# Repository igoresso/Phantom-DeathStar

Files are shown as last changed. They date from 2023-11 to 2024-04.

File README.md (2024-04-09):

<p align="center">
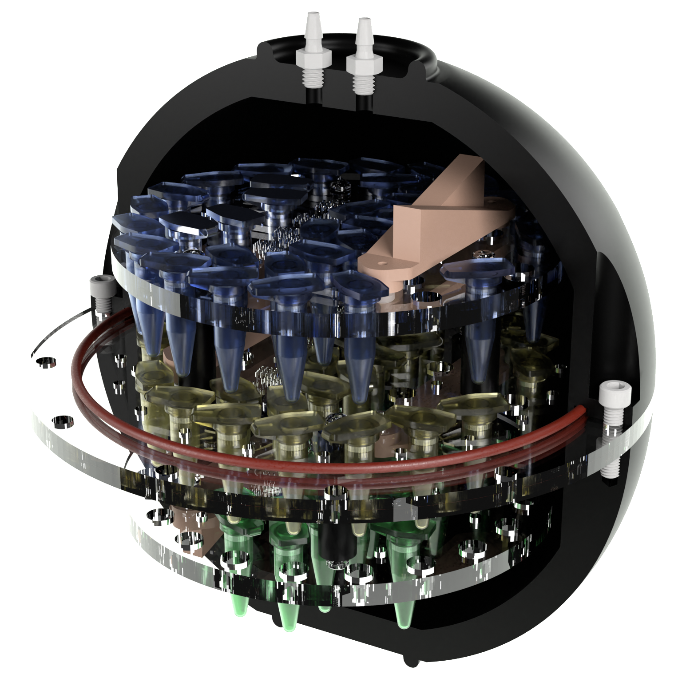
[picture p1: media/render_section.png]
Death Star phantom
  
</p>

# "Death Star" Imaging Phantom 

Welcome to our GitHub repository showcasing the development of a universal MRI imaging phantom, meticulously crafted to cater to a spectrum of research and clinical needs. This phantom presents a multilayered architecture nestled within a spherical shell, promising versatility and adaptability for MRI experimentation and calibration endeavours.

## Features

- Multilayered structure enclosed in a spherical shell
- Outer diameter of 170mm, optimised for compatibility with smaller head coils
- Three layers with multiple mounting holes for various modules and a coarse resolution grid on each
- Top and bottom layers affixed to the middle disc, snugly ensconced between the hemispheres, and reinforced with two silicone o-rings to prevent leakage
- Two tube fittings facilitate easy assembly and disassembly, with one designated for air release during refilling
- Utilising 0.5mL Eppendorf tubes to store any liquids of interest such as T1, T2, or proton density arrays
- The spherical shell is machined on a CNC lathe, while the discs are laser-cut from a 6mm acrylic sheet
- To achieve the desired precision, the resolution grids on the discs are added using a CNC mill, ensuring accuracy

## Additional modules

- Each disc features mounting holes for additional modules, facilitating further customisation and experimentation.
- Extra modules can be 3D printed using a consumer SLA printer
- Two modules are provided: a fine-resolution grid and a slice profile double-wedge
- A template for custom module design is provided

## Bill of Materials

| Part | Quantity |
| --- | --- |
| Acetal rod 250mm (180mm diameter) | 1 |
| Acetal rod 100mm (10mm diameter) | 1 |
| Acrylic sheet 6mm | 1 |
| Glass-Filled Nylon Socket Head Screws M5×0.8, 20mm | 12 |
| Impact-Resistant Polycarbonate Pan Head Phillips Screws M3×0.5, 10mm | 24 |
| Tight-Seal Moisture-Resistant Acetal Barbed Tube Fitting M6×1 | 2 |
| Eppendorf tube 0.5ml | As required |

## Assembly video

https://github.com/igoresso/Phantom-DeathStar/assets/33253240/f2b40d54-d948-43c9-96b6-33f2290663dc

## Acknowledgements

The authors acknowledge the facilities and scientific and technical assistance of the National Imaging Facility, a National Collaborative Research Infrastructure Strategy (NCRIS) capability, at the Melbourne Brain Centre Imaging Unit, University of Melbourne.

## Licensing

The materials are shared under the Creative Commons license which enables reusers to distribute, remix, adapt, and build upon the material in any medium or format for noncommercial purposes only, and only so long as attribution is given to the creator. If you remix, adapt, or build upon the material, you must license the modified material under identical terms.

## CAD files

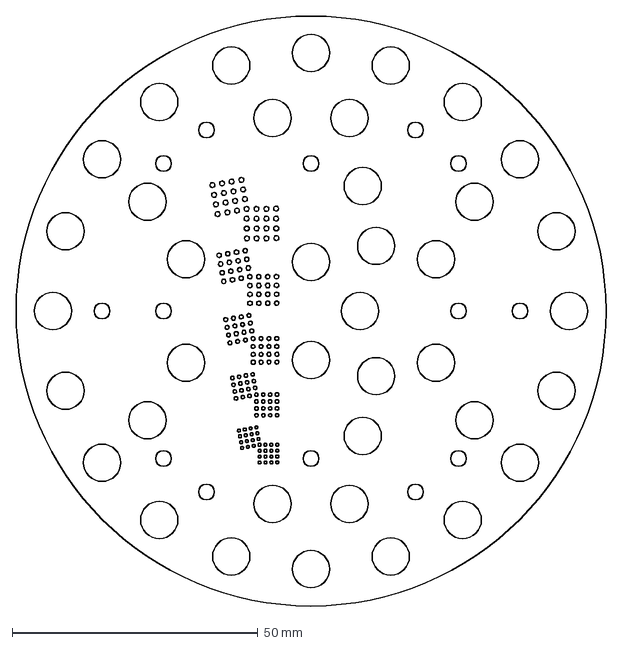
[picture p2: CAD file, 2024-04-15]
CAD/SmallDisc.dxf
120.0 x 120.0 mm

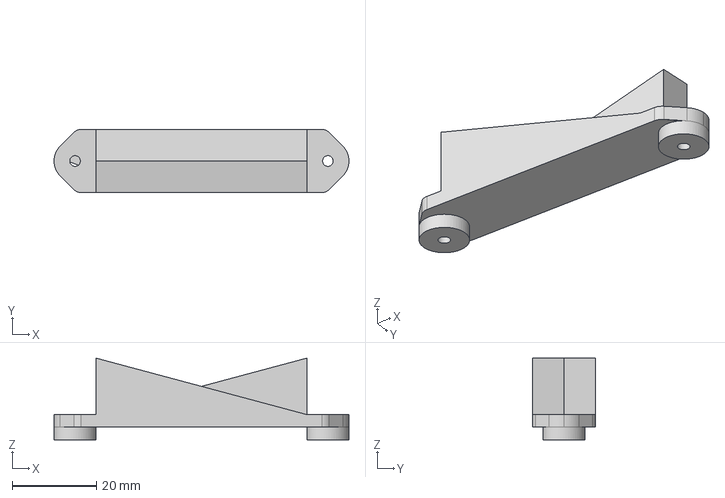
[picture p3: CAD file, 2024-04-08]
CAD/WedgeModule.step
70.0 x 15.0 x 19.4 mm

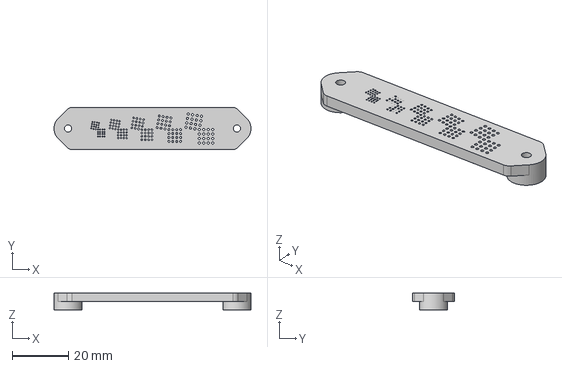
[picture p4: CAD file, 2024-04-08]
CAD/ResolutionModule.step
70.0 x 15.0 x 6.00 mm

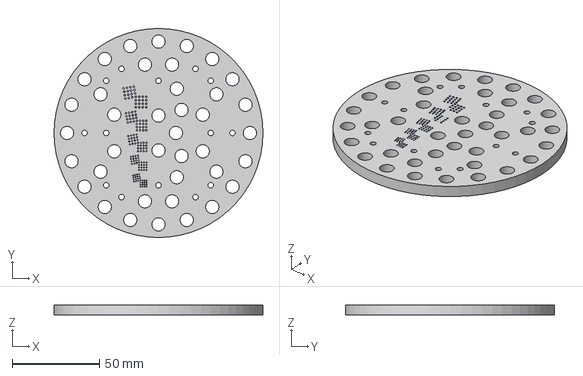
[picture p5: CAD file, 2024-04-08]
CAD/SmallDisk.step
120.0 x 120.0 x 6.00 mm

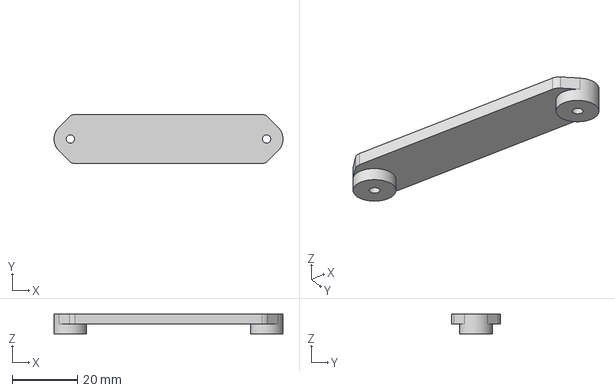
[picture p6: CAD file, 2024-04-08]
CAD/TemplateModule.step
70.0 x 15.0 x 6.00 mm

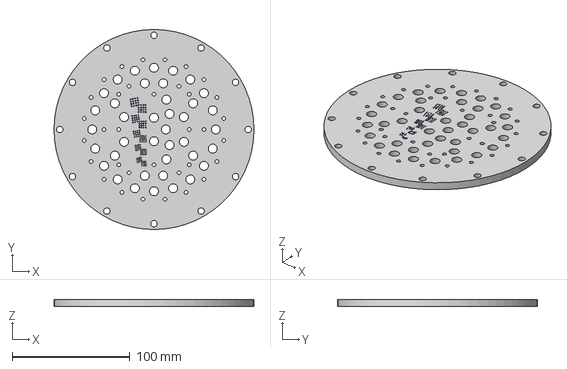
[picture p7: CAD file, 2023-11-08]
CAD/MiddleDisc.step
170.0 x 170.0 x 6.00 mm

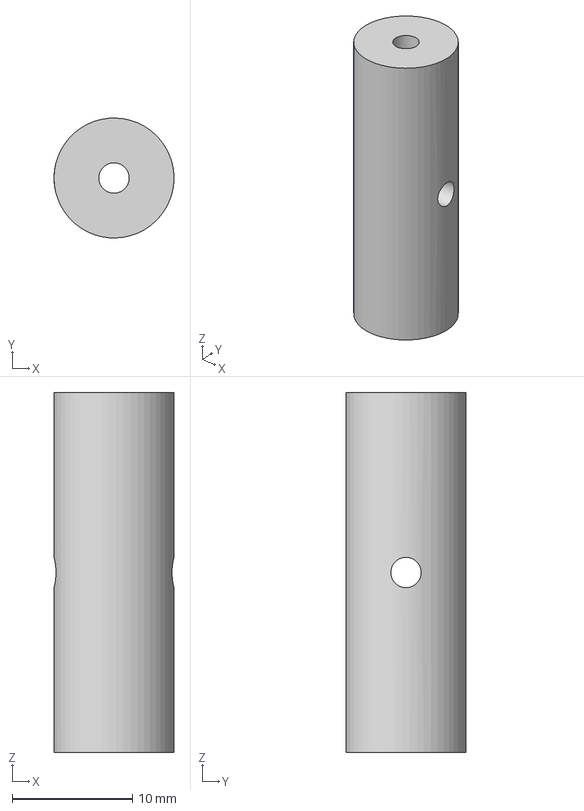
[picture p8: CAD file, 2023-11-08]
CAD/Pillar.step
10.00 x 10.00 x 30.0 mm

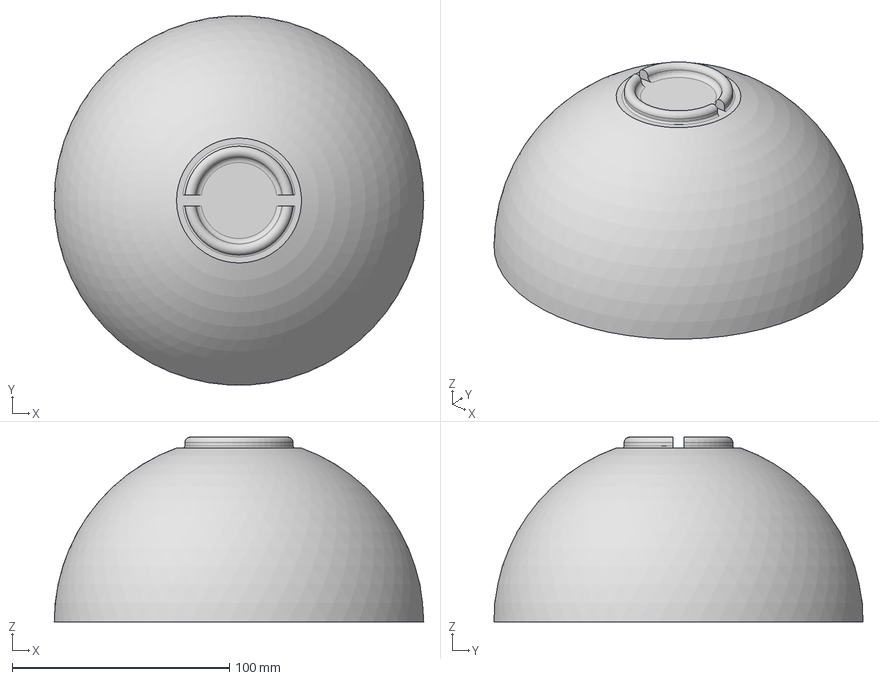
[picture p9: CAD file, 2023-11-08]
CAD/BottomHemisphere.step
170.0 x 169.8 x 85.0 mm

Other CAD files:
CAD/MiddleDisc.dxf

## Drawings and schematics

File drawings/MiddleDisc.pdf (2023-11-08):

B 0.1

A | A (2:1) | 0.025

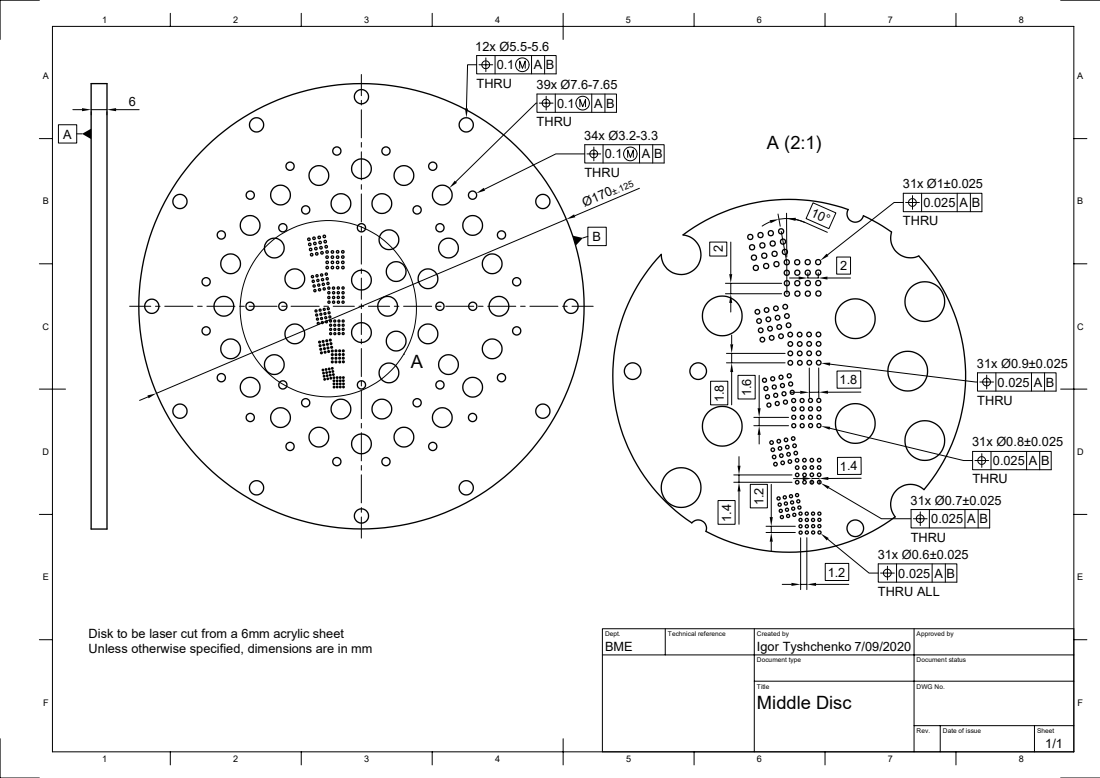
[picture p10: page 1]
F Dept.; Technical reference; Created by; Approved by Document type; Document status Title; DWG No. Rev.; Date of issue; Sheet 7/09/2020; 1/1 Middle Disc BME; Igor Tyshchenko Disk to be laser cut from a 6mm acrylic sheet Unless otherwise specified, dimensions are in mm; B 39x Ø7.6-7.65 THRU; B 34x Ø3.2-3.3 THRU; B 31x Ø0.6±0.025 THRU ALL; B 31x Ø0.7±0.025 THRU 0.025; B 31x Ø1±0.025 THRU 0.1; B 12x Ø5.5-5.6 THRU; B 31x Ø0.8±0.025 THRU0.025; B 31x Ø0.9±0.025 THRU

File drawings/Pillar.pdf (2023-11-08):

A A

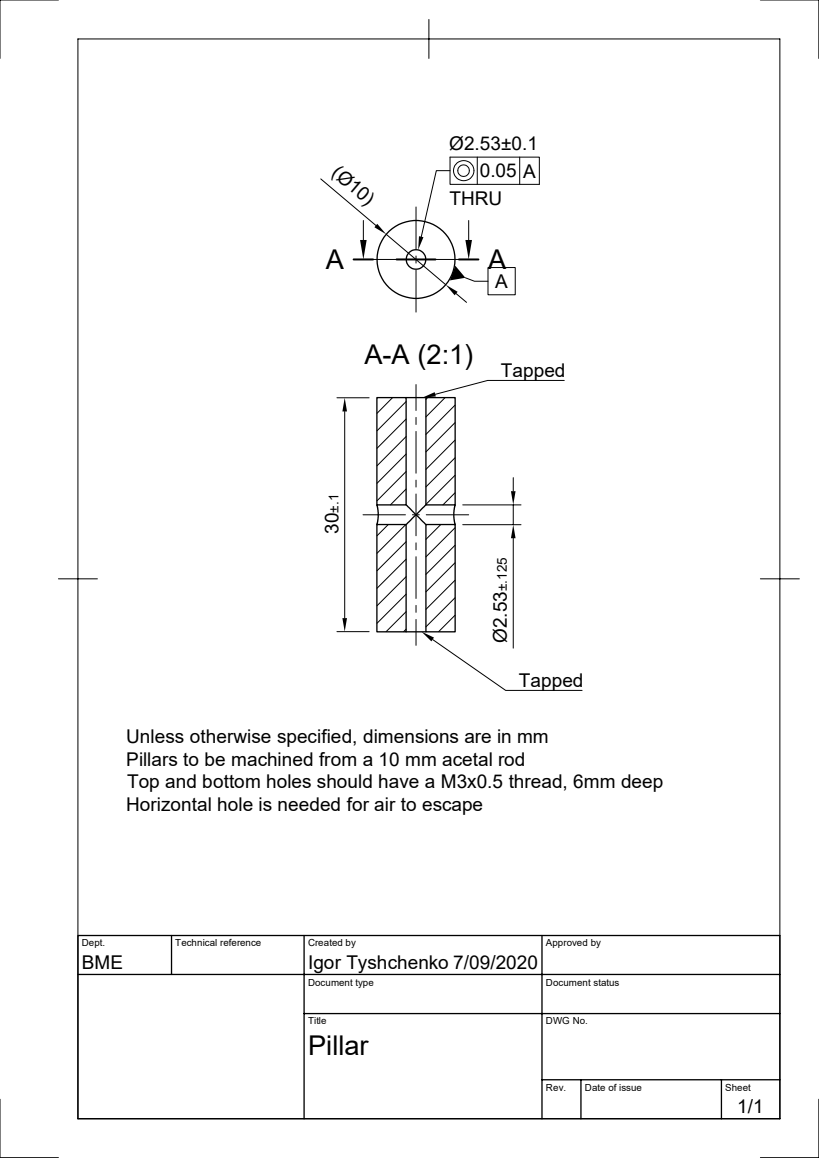
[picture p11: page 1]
Dept.; Technical reference; Created by; Approved by; BME; Igor Tyshchenko; THRU; A A-A (2:1) Ø².53±.125 Tapped; Tapped ³⁰±.1

Unless otherwise specified, dimensions are in mm
Pillars to be machined from a 10 mm acetal rod
Top and bottom holes should have a M3x0.5 thread, 6mm deep
Horizontal hole is needed for air to escape

Document type | Document status

Title Pillar | DWG No.

Rev. | Date of issue | Sheet 1/1

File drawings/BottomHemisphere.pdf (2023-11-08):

## 1 A

2 | 3 | 4 | 5 | 6 | 7 | 8 1 | 2

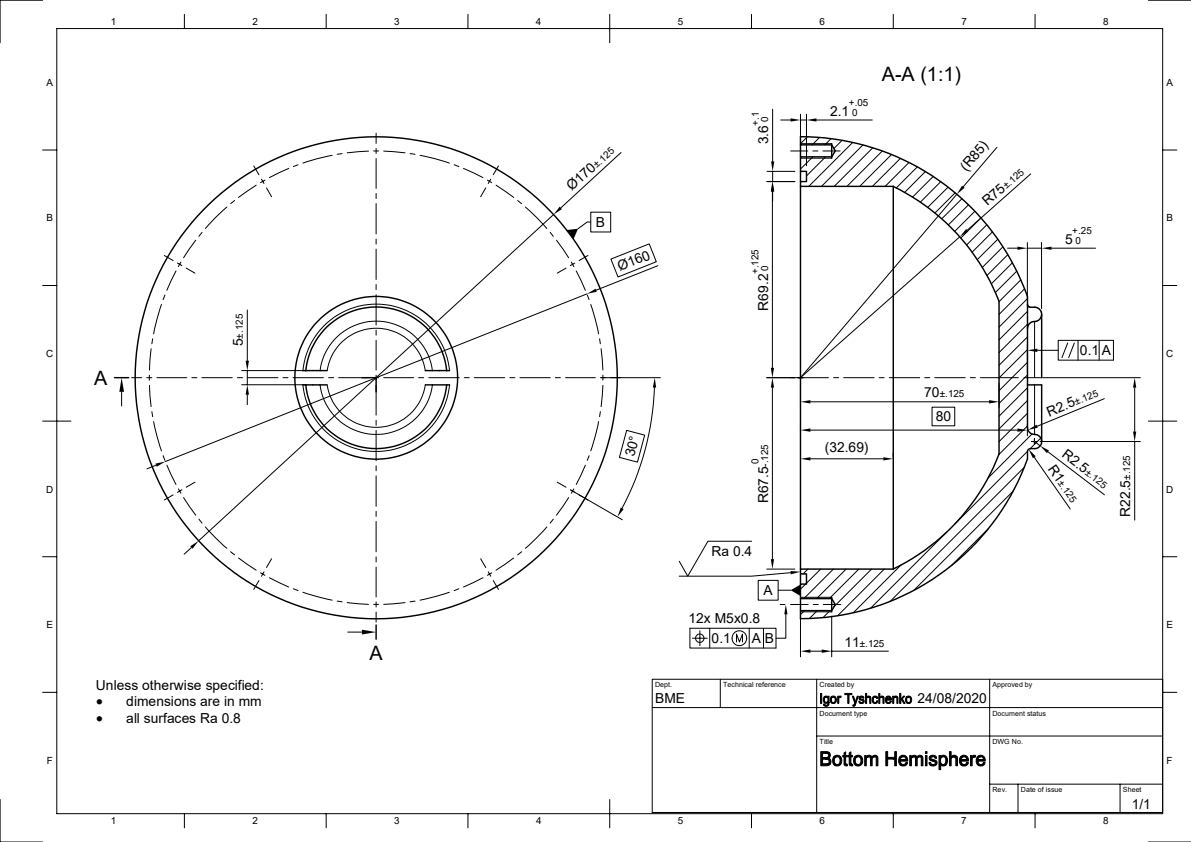
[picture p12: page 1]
F Dept.; Technical reference; Created by; Approved by Document type; Document status Title; DWG No. Rev.; Date of issue; Sheet 24/08/2020; 1/1 BME

5±.125 Unless otherwise specified: · dimensions are in mm

· all surfaces Ra 0.8

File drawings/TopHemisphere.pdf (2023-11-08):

## 1 A

2 | 3 | 4 | 5 | 6 | 7 | 8 1 | 2

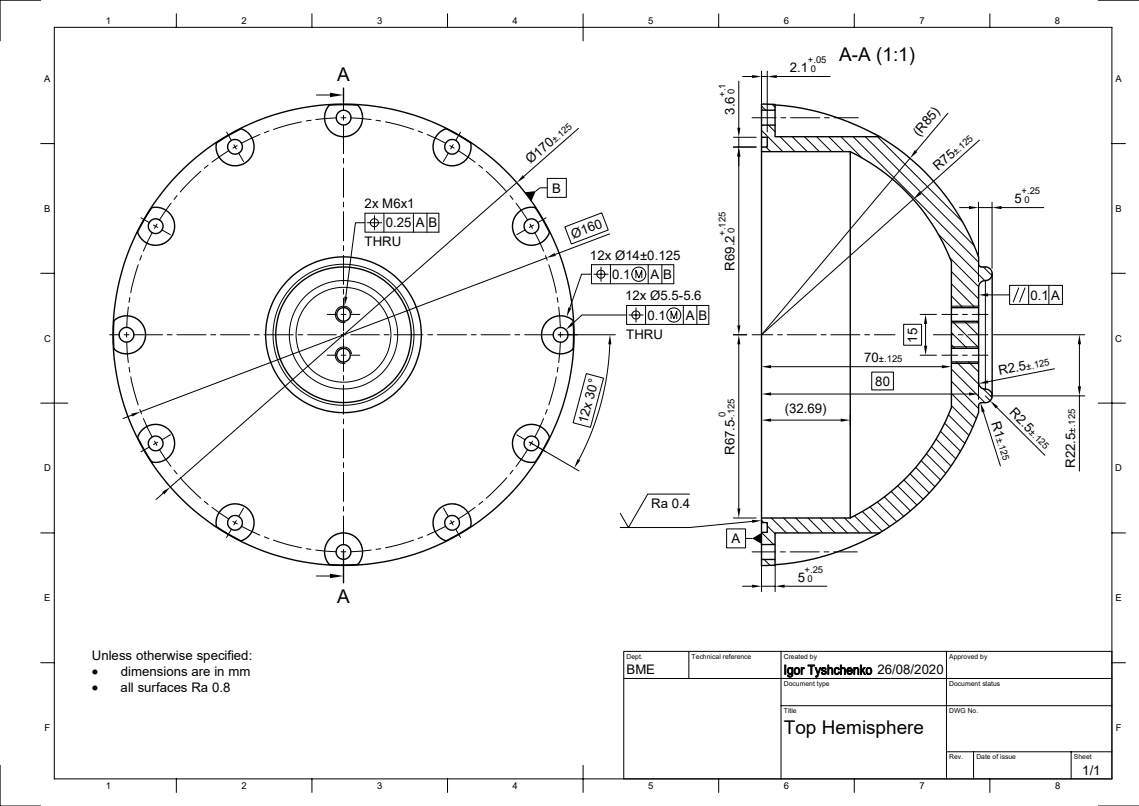
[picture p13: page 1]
F Dept.; Technical reference; Created by; Approved by Document type; Document status Title; DWG No. Rev.; Date of issue; Sheet 26/08/2020; 1/1 Top Hemisphere BME Unless otherwise specified: ·; dimensions are in mm; B 12x Ø5.5-5.6 THRU 0.1; B 2x M6x1 THRU

· all surfaces Ra 0.8

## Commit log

2024-04-08 Added renders and updated CAD files
    [MiddleDisc-noREsolutionGrid-smallerHoles.dxf, MiddleDisc-noREsolutionGrid.dxf, ResolutionModule.step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]
2024-04-08 Remove .DS_Store from current directory
2024-04-15 Updated the Small Disk
    [SmallDisc.dxf]

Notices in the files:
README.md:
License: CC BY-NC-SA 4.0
